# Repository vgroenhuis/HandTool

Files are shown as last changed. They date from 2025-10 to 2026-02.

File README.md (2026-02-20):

# HandTool
Handheld 6 DOF input device for robot control applications.

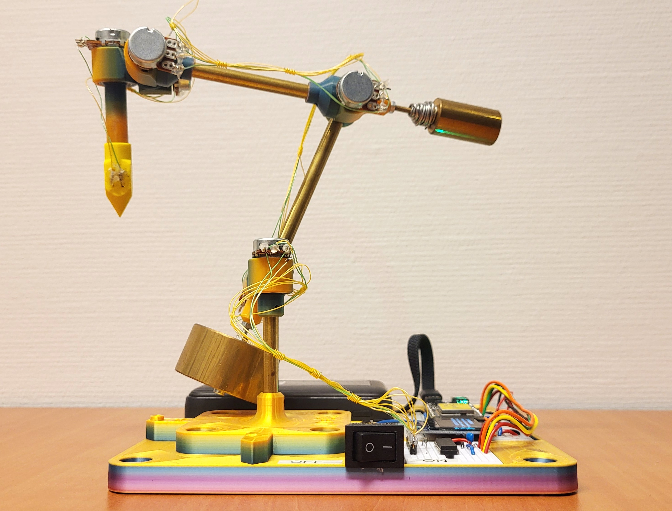
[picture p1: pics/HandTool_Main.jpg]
HandTool main view


# Introduction

HandTool is a 6 DOF input device intended for manipulating robot arms and other applications involving manipulation of rigid bodies. It is low-cost and fully open source.

The tool has six potentiometers connected together with 3D printed parts and brass shafts. The tool is balanced by two masses so that it mostly stays in position when released. It also has a pushbutton in the tip, intended to enable/disable dragging of some controlled object.

The tool is WiFi enabled; the microcontroller serves webpages and provides several HTTP endpoints providing data in JSON format. The idea is that it could dynamically connect to other WiFi-enabled robot arms.

# Electronics

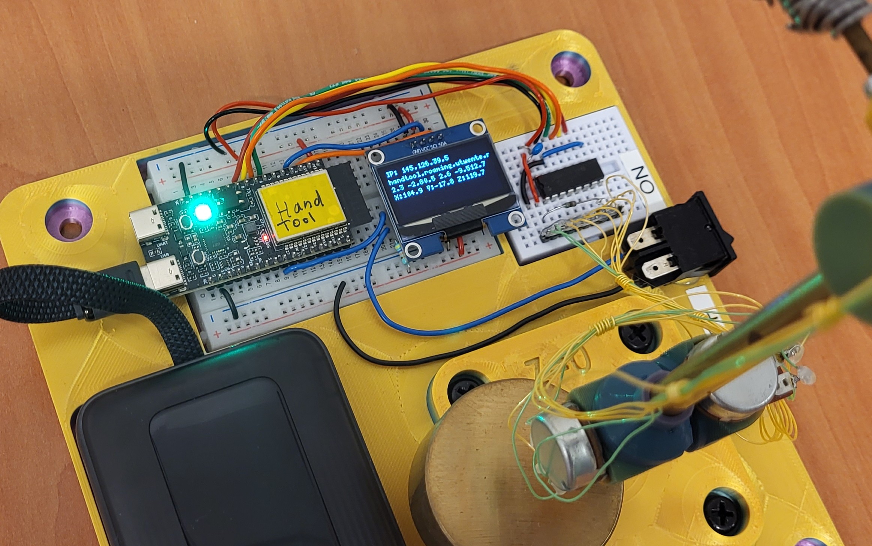
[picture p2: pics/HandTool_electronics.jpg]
HandTool main view


The microcontroller is an ESP32-C5-DevKitC-1. It is chosen for its 5 GHz WiFi capabilities, which is essential inside university buildings due to congestion in the 2.4 GHz band. A MCP3008 A/D unit measures the potentiometer values while a 1.3" OLED displays some status information.

# User interface

THe main user interface is accessed in a web browser at the device's address. The device connects to university's iotroam network, registered at iotroam.nl. A hostname can be coupled to its MAC address to give it a static hostname, such as handtool.roaming.utwente.nl . The IP address is also displayed on the screen, which is useful as it is dynamic and a change in IP address takes a few minutes to propagate through the DNS servers.

## 3D robot view

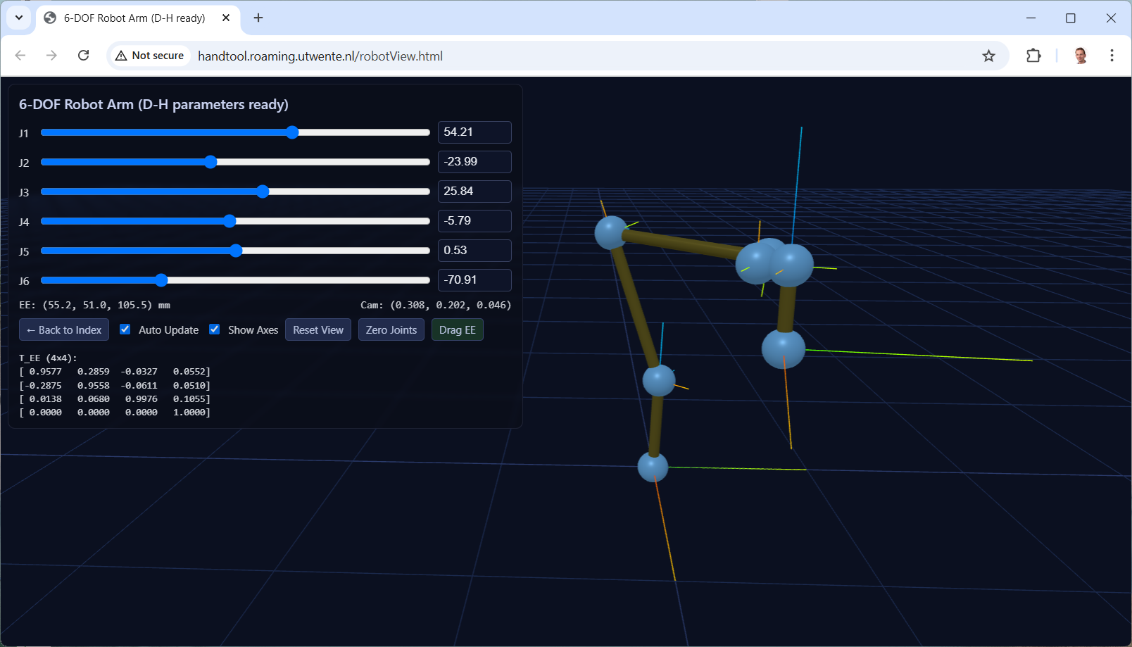
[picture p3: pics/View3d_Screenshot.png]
3D robot view


This screenshot shows a schematic rendering of the HandTool. If it is not connected, the sliders can be used to manipulate it.

## HTTP endpoints

The following HTTP endpoints are available:

- / Main page.
- /index.html Main page, same as /
- /robotView.html Open Robot View (3D)
- /allData JSON structure with all available data
- /angles JSON structure with joint angles in degrees
- /rawAdcValues JSON structure with raw ADC values
- /fk JSON structure with end-effector to robot coordinate transformation matrix
- /dhParams JSON structure with D-H parameters of the HandTool
- /serialAngles Enable/disable outputting angles to serial port
- /serialFK Enable/disable outputting end-effector coordinate frame to serial port
- /serialFrequency Control frequency of serial data

## Bill of Materials

1. 6x potmeter: WH148 compatible, 10KΩ. I used R16148-1A-2-B10K.
2. 6x ball bearing: 6700ZZ or equivalent. 15x10x4 mm.
3. Brass tubes, outer diameter 7 mm, wall thickness 0.5 mm. Lengths: 54 mm, 76 mm, 90 mm.
4. M3 threaded rod for small counterweight, 50 mm.
5. M3 screw (cheese head) for large counterweight, 44 mm. (Use 50 mm, cut to length).
6. Several M3 nuts.
7. M2 screw, 16 mm (to properly fix brass rods in joints).
8. M6 screws for mounting the base (flat head).

## Assembly instructions

3D print parts. Solidworks, STEP and 3MF files are available [here](CAD/v1_2024). Note that the JointHousing Solidworks file has six distinct configurations, with a total of nine printed parts. The pictured version was printed in rainbow PLA filament, starting with purple/blue on the buildplate and extending towards yellow. No supports are needed, but a brim is generally required.

7 mm brass rods (wall thickness 0.5 mm) are mostly press fitted in 3d printed parts. If the press fit becomes too loose then you can drill a small (1.8 or 1.9 mm) hole so you can tighten it with a M2 screw.

Small and large counterweights are custom made of brass in a workshop using a lathe. Use M3 threaded rods and/or screws and nuts to rigidly attach these to the correct joint. First balance the top part with the small counterweight by adjusting the separation distance. Then balance the whole hand tool with the large counterweight.

Electric wires should be thin and flexible. Solder these to the potentiometer leads and apply hot glue as stress relief, or else the wires may break off at the solder joints.

## History

The HandTool was first developed in 2024 to actuate a robot arm with identical kinematic configuration (apart from a scaling factor), so that direct joint control was possible and no forward/inverse kinematics was needed. See video [here](https://utwente.yuja.com/v/MamriRobot). The HandTool went through four iterations before arriving at v1.0. Earlier versions were not counter-weighted, but used friction in the joints to keep the given pose.

## Roadmap

Upcoming features

- Implement HTTP authentication.
- Improved design with more off-the-shelf parts instead of customized parts. Especially counterweights and links.
- Dedicated PCB for electronics.
- Calibrate zero position in software, saving offsets in filesystem.
- Additional communication protocols.
  - Examples: Bluetooth, MQTT, ROS2, ...
  - Want to implement it yourself? Clone the repository, implement it and make a pull request!

## Phyiscal devices

First HandTool at RaM [handtool.roaming.utwente.nl](http://handtool.roaming.utwente.nl/) (accessible from within University of Twente's network)

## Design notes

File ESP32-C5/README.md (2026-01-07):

# HandTool (ESP32-C5)

This repository contains firmware and resources for the HandTool project targeting the ESP32-C5.

Below is an image of the Hand Tool:

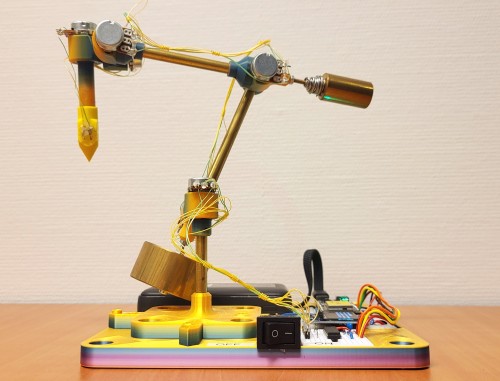
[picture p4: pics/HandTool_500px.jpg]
HandTool


The file `src/WifiCredentials.h` is not under version control. You can make your own. Example contents:

```
{
#pragma once
#define WIFI_CREDENTIALS {{"ssid","password"},{"ssid2","pasword2"}}
#define ADMIN_CREDENTIALS {"admin",""}
#define ALIAS_URL "https://raw.githubusercontent.com/vgroenhuis/roaming-wifi-manager/refs/heads/main/aliases/bssid_info.json"
}
```

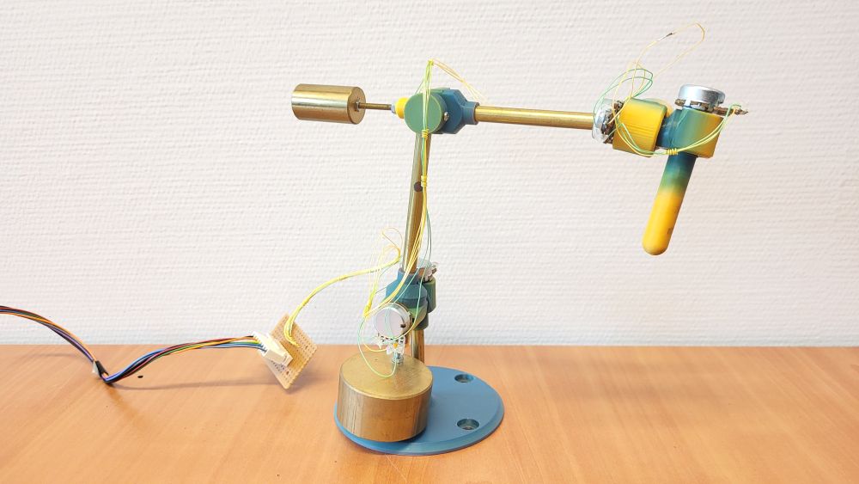
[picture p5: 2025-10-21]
pics/HandTool_1000px.jpg

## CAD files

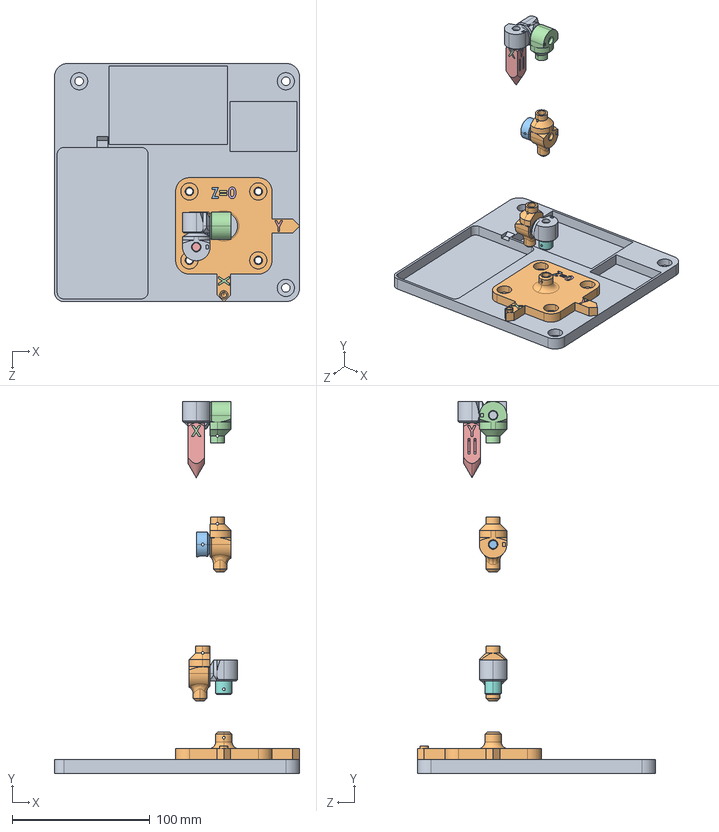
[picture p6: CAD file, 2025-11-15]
CAD/v1.1_2025/HandTool_With_Electronics_Assembly.STEP
178.0 x 270.0 x 173.0 mm
FrameForElectronics
Base_large
StickWithButton_J1bottom
StickWithButton_J1top_J5_J6 x 3
StickWithButton_J2_J3_Counterweight x 2
StickWithButton_J3bottom
StickWithButton_J2_J3
Stick2WithButton

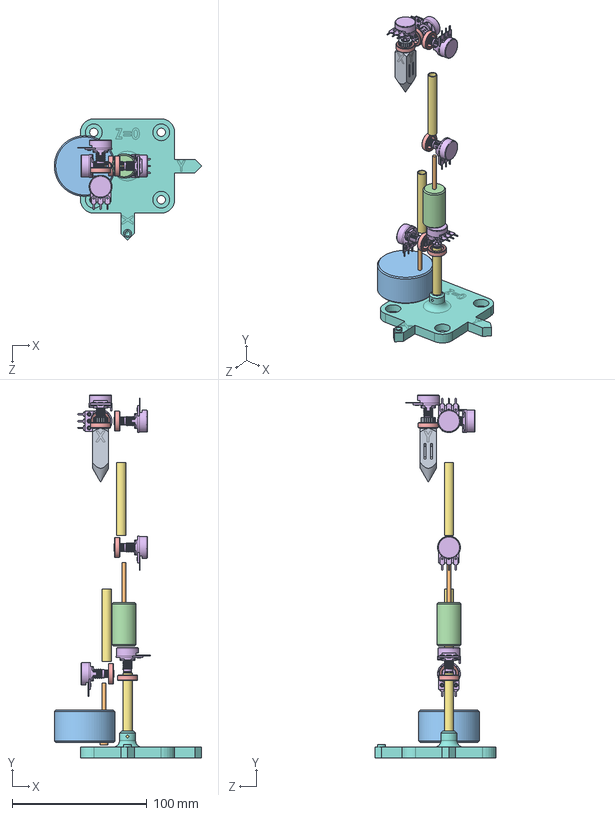
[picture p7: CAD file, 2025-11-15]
CAD/v1.1_2025/HandTool_Assembly.SLDASM
109.3 x 269.4 x 90.0 mm
Base_large
BrassLink x 3
Potmeter10K x 6
Bearing_6700ZZ x 6
CounterweightSmall
CounterweightLarge
M3_Rod x 2
Stick2WithButton

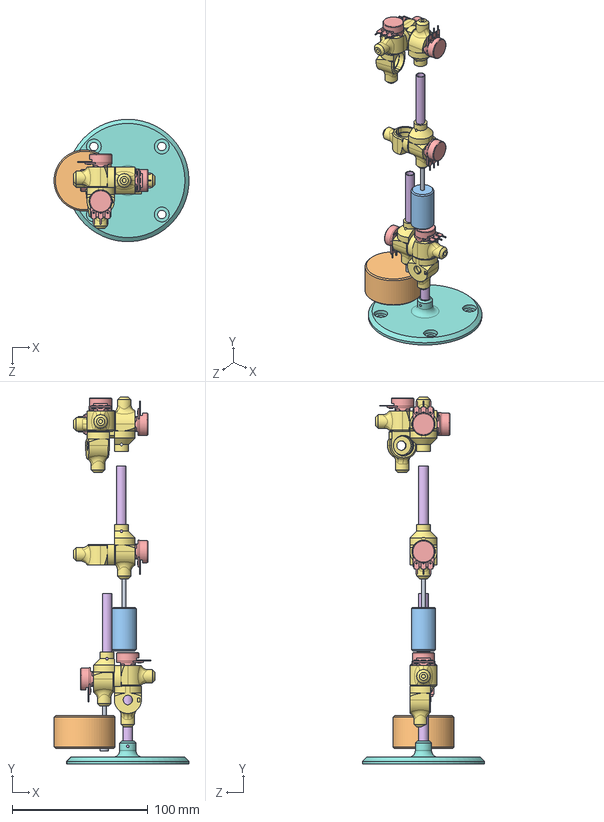
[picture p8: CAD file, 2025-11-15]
CAD/v1_2024/HandTool_Assembly.SLDASM
99.3 x 270.0 x 90.0 mm
Base
JointHousing x 9
BrassLink x 3
Potmeter10K x 6
Bearing_6700ZZ x 6
CounterweightSmall
CounterweightLarge
M3_Rod x 2

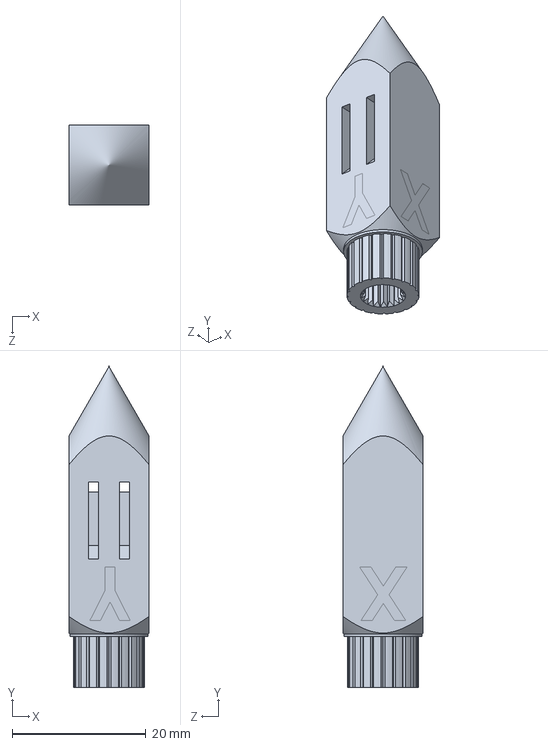
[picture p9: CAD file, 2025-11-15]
CAD/v1.1_2025/Stick2WithButton.SLDPRT
12.0 x 48.0 x 12.0 mm

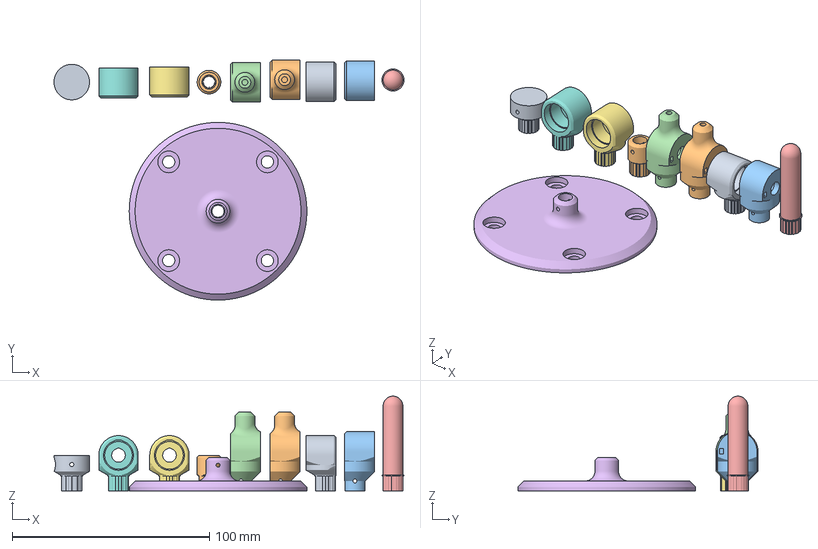
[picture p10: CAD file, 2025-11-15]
CAD/v1_2024/HandTool_PrintedParts_BambuSlicer.3mf
177.3 x 121.7 x 48.0 mm
JointHousing_J1top_J5_J6 x 3
JointHousing_J2_J3_Counterweight x 2
JointHousing_J2_J3
JointHousing_Stick
Base
JointHousing_J3bottom
JointHousing_J1bottom

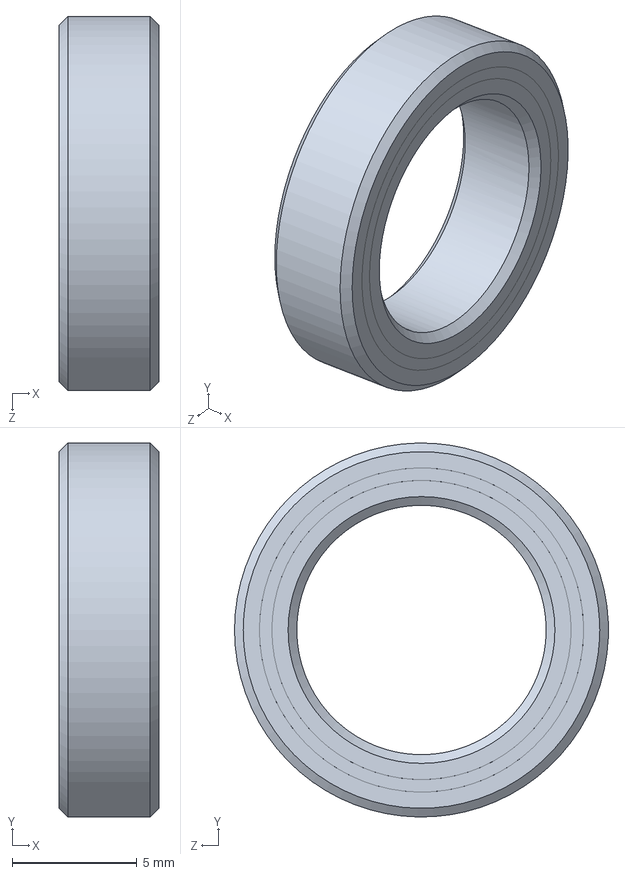
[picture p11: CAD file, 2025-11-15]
CAD/v1.1_2025/Bearing_6700ZZ.SLDPRT
4.00 x 15.0 x 15.0 mm

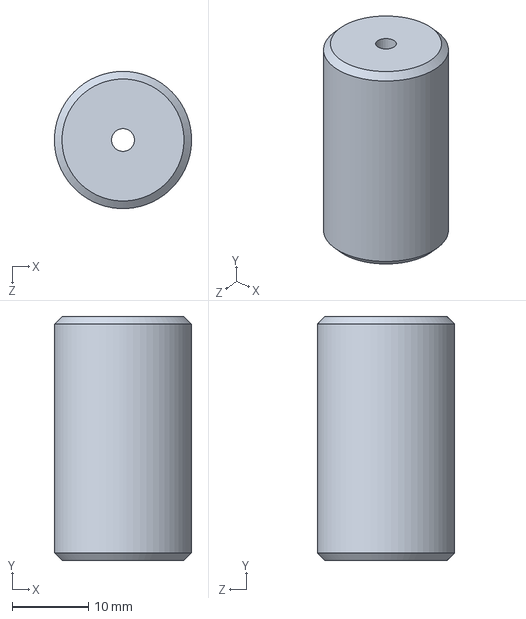
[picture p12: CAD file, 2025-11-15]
CAD/v1.1_2025/CounterweightSmall.SLDPRT
18.0 x 32.0 x 18.0 mm

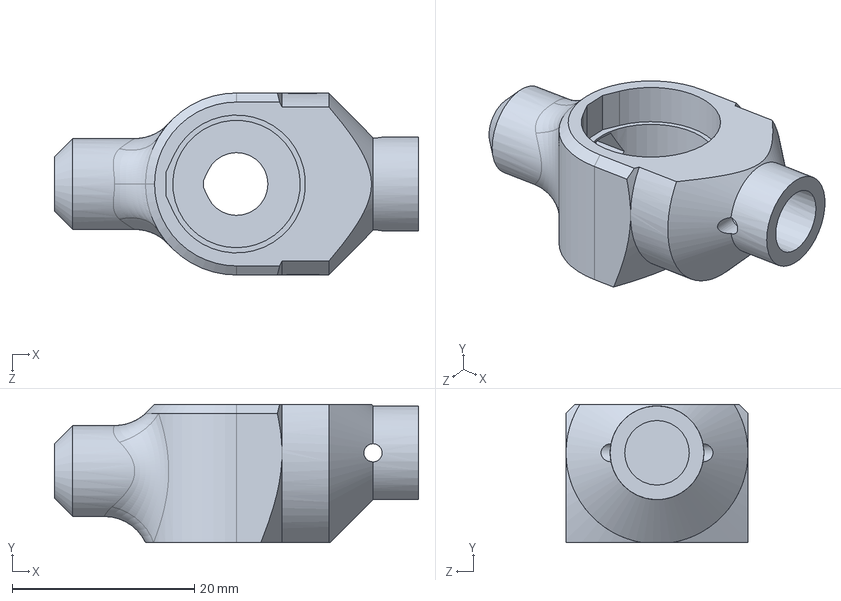
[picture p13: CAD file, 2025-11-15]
CAD/v1_2024/JointHousing.SLDPRT
40.0 x 15.2 x 20.0 mm

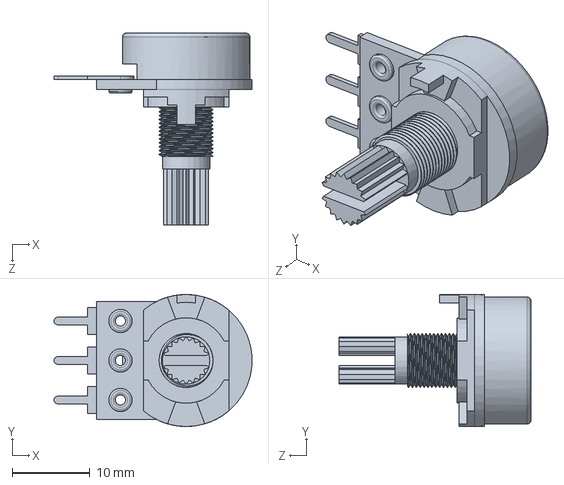
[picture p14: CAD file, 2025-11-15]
CAD/v1.1_2025/Potmeter10K.SLDPRT
25.5 x 17.0 x 24.7 mm

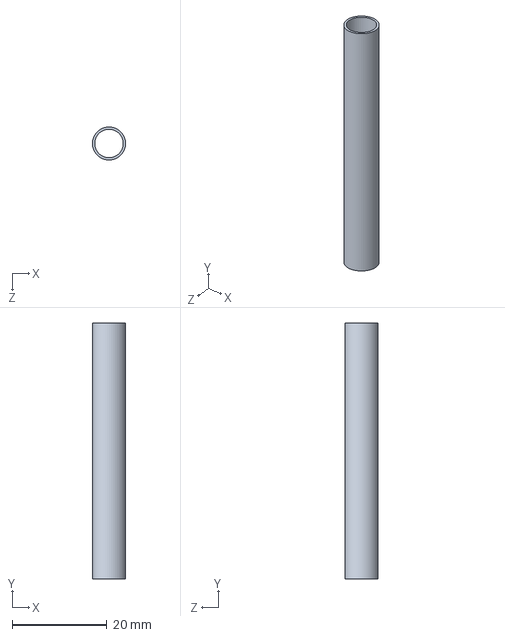
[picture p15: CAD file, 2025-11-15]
CAD/v1.1_2025/BrassLink.SLDPRT
6.99 x 54.0 x 7.00 mm

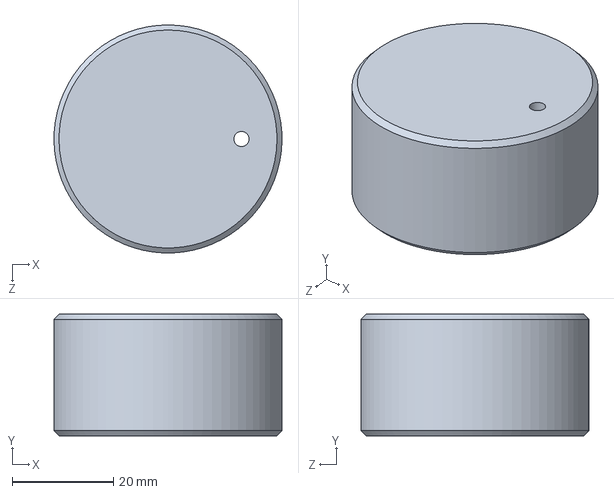
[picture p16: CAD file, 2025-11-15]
CAD/v1_2024/CounterweightLarge.SLDPRT
45.0 x 24.0 x 45.0 mm

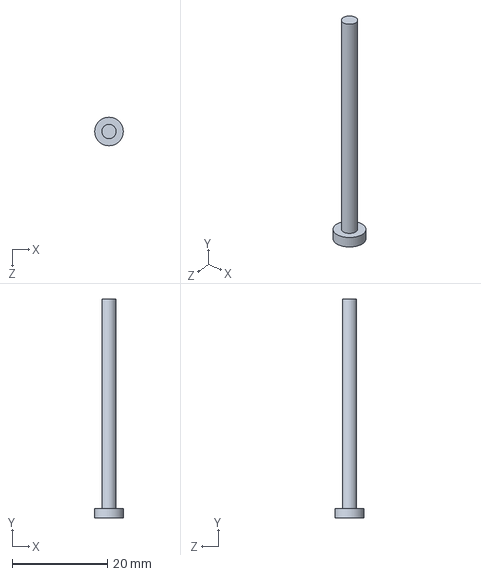
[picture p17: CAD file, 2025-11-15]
CAD/v1_2024/M3_Rod.SLDPRT
5.99 x 46.0 x 6.00 mm

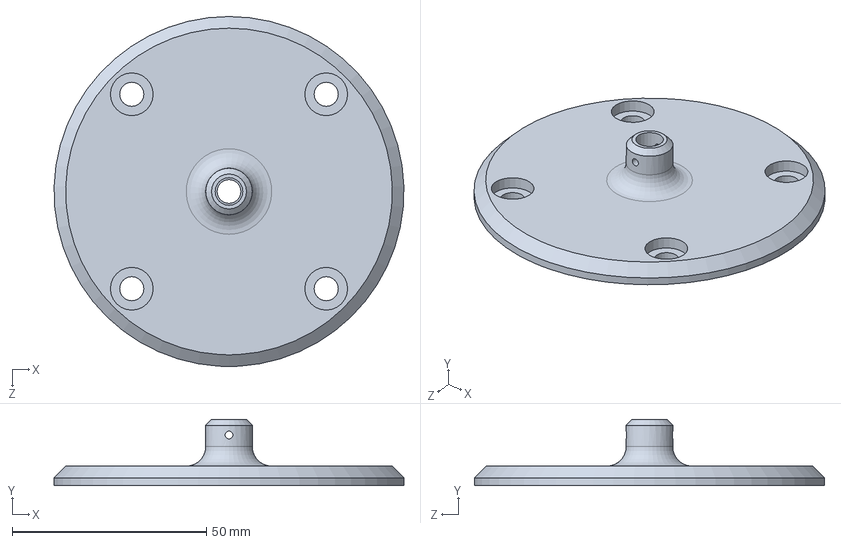
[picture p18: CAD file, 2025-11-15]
CAD/v1_2024/Base.SLDPRT
90.0 x 17.0 x 90.0 mm

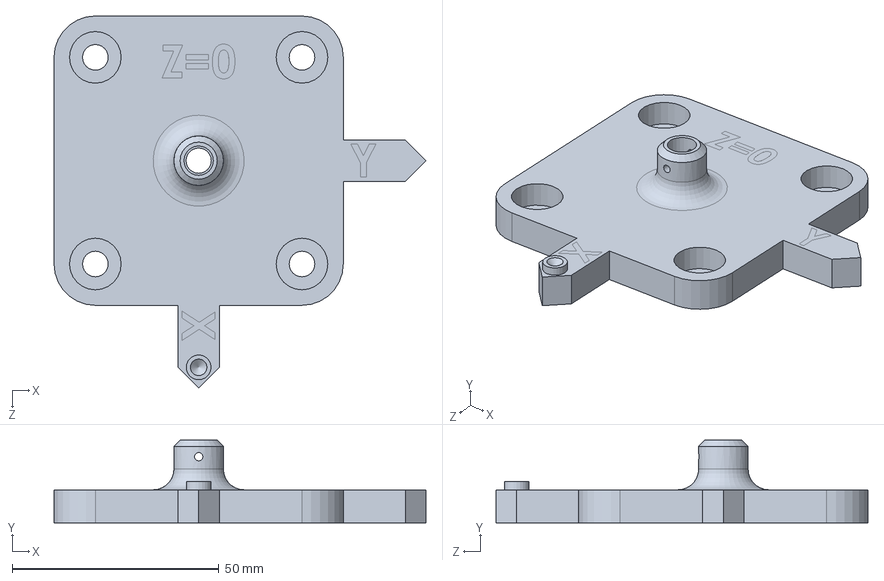
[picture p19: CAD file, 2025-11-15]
CAD/v1.1_2025/Base_large.SLDPRT
90.0 x 20.0 x 90.0 mm

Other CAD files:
CAD/v1_2024/Potmeter10K.SLDPRT
CAD/v1.1_2025/FrameForElectronics.SLDPRT
CAD/v1.1_2025/HandTool_With_Electronics_Assembly.SLDASM
CAD/v1.1_2025/Stick2WithButton_Adapter.SLDPRT
CAD/v1.1_2025/StickWithButton.SLDPRT
CAD/v1_2024/HandTool_PrintedParts.STEP

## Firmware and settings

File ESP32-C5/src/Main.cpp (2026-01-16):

#include <Arduino.h>
#include "WifiServer.h"
#include "Adc.h"
#include "Display.h"
#include "Kinematics.h"
#include <LittleFS.h>
#include <esp_sleep.h>

/*
void sleep_setup() {   
    esp_sleep_enable_ext1_wakeup_io(1<<4, ESP_EXT1_WAKEUP_ANY_LOW);
}
*/

/*
bool isPowerSwitchOn() {
    return digitalRead(4) == LOW;
}
*/

void init_file_system() {
    if (!LittleFS.begin(true, "/littlefs", 10, "littlefs")) {
        Serial.println("LittleFS Mount Failed");
    } else {
        //Serial.println("LittleFS Mounted Successfully");
    }
}

void setupHandTool() {
    //rgbLedWrite(LED_BUILTIN, 255, 255, 255);
    //rgbLedWrite(LED_BUILTIN, 255, 0, 0);
    Serial.begin(115200);
    delay(100);
    //sleep_setup();
    init_file_system();
    display_setup();
    robot_setup();
    kinematics_init();
    wifi_setup();
}

//if (isPowerSwitchOn()) {
        //rgbLedWrite(LED_BUILTIN, 30, 10, 0); // Orange during setup
    //}
    //rgbLedWrite(LED_BUILTIN, 0, 10, 0); // Green when setup complete



void setup() {
    analogReadResolution(12);
    pinMode(A5, INPUT); // Battery voltage ADC
    setupHandTool();
}

void printValuesPeriodically() {
    static unsigned long lastPrinted = 0;
    if (millis() - lastPrinted >= 1000) {
        lastPrinted = millis();
        // Print ADC readings to Serial
        Serial.print("Raw ADC:");
        for (uint8_t ch = 0; ch < 8; ++ch) {
            Serial.printf(" CH%u=%u", ch, raw_adc[ch]);
        }
        Serial.printf(" Battery: ADC5=%d Voltage=%.2fV", analogRead(A5), getBatteryLevel());
        Serial.println();
    }
}

/*
void startDeepSleep() {
    delay(10);
    display_message("Going to sleep...");
    WiFi.disconnect(true);
    WiFi.mode(WIFI_OFF);
    //rgbLedWrite(LED_BUILTIN, 255, 255, 255);
    delay(500);
    rgbLedWrite(LED_BUILTIN, 0, 0, 0);
    display_off();
    delay(10);
    esp_deep_sleep_start();
}

void testDeepSleep() {
    if (!isPowerSwitchOn()) {
        startDeepSleep();
    }
}
*/

void loopHandTool() {
    //testDeepSleep();
    sensors_loop();
    display_loop();
    wifi_loop();
    //printValuesPeriodically();
    //delay(1);
}

void loop() {
    loopHandTool();
}

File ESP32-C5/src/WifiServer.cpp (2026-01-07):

#include "WifiServer.h"
// #include <WiFi.h>
// #include <WebServer.h>
#include <Arduino.h>
// #include <HTTPClient.h>
// #include <WiFiClientSecure.h>
#include "Adc.h"
#include <LittleFS.h>
#include "Display.h"
#include "Kinematics.h"

#ifndef DISABLE_WIFI
RoamingWiFiManager manager;
#endif

/*
static unsigned long s_lastReconnect = 0;
static unsigned long s_lastStatusPing = 0;
*/

/*
WebServer server(80);
WiFiClientSecure client; // TLS required by server
HTTPClient heartbeatHttp;
bool heartbeatInitialized = false;
*/

// Serial output control flags
bool serialOutputAngles = false;
bool serialOutputFK = false;
unsigned long lastSerialOutput = 0;
unsigned long serialOutputInterval = 100; // ms between outputs (default 10Hz)

/*
const char* wifi_mac() {
    static String m;
    m = WiFi.macAddress();
    return m.c_str();
}

const char* wifi_ip() {
    static String ip;
    ip = WiFi.localIP().toString();
    return ip.c_str();
}

bool wifi_is_connected() {
    return WiFi.status() == WL_CONNECTED;
}
*/

// HTTP handler for /rawAdcValues - returns JSON with raw ADC readings
void handleRawAdcValues(AsyncWebServerRequest *request) {
    String json = "{";
    json += "\"valid\": ";
    json += mcp3008_present ? "true" : "false";
    json += ",";
    json += "\"values\": [";
    for (int i = 0; i < 8; ++i) {
        json += String(raw_adc[i]);
        if (i < 7) json += ",";
    }
    json += "]";
    json += "}";
    request->send(200, "application/json", json);
}

void handleFilteredAdcValues(AsyncWebServerRequest *request) {
    String json = "{";
    json += "\"valid\": ";
    json += mcp3008_present ? "true" : "false";
    json += ",";
    json += "\"values\": [";
    for (int i = 0; i < 8; ++i) {
        json += String(filtered_adc[i]);
        if (i < 7) json += ",";
    }
    json += "]";
    json += "}";
    request->send(200, "application/json", json);
}

// HTTP handler for /angles - returns JSON with six joint angles in degrees
void handleAngles(AsyncWebServerRequest *request) {
    String json = "{";
    json += "\"valid\": ";
    json += mcp3008_present ? "true" : "false";
    json += ",";
    json += "\"dragButtonPressed\": ";
    json += dragButtonPressed ? "true" : "false";
    json += ",";
    json += "\"angles\": [";
    for (int i = 0; i < 6; ++i) {
        json += String(angles_deg[i], 2);
        if (i < 5) json += ",";
    }
    json += "]";
    json += "}";
    request->send(200, "application/json", json);
}

// HTTP handler for /fk - returns JSON with 4x4 transformation matrix from base to end-effector
void handleForwardKinematics(AsyncWebServerRequest *request) {
    //float joint_angles[6];
    //for (int i = 0; i < 6; ++i) {
    //   joint_angles[i] = angles_deg[i];
    //}
    
    // Compute forward kinematics
    Matrix4x4 T = IDENTITY_MATRIX;
    //matrix_identity(T);

    if (mcp3008_present) {
        T = compute_forward_kinematics(angles_deg);
    }

    // Build JSON response with 4x4 matrix structure
    String json = "{";
    json += "\"valid\": ";
    json += mcp3008_present ? "true" : "false";
    json += ",";
    json += "\"dragButtonPressed\": ";
    json += dragButtonPressed ? "true" : "false";
    json += ",";
    json += "\"matrix\": [";
    for (int row = 0; row < 4; ++row) {
        json += "[";
        for (int col = 0; col < 4; ++col) {
            json += String(T.m[row][col], 6);  // 6 decimal places
            if (col < 3) json += ",";
        }
        json += "]";
        if (row < 3) json += ",";
    }
    json += "]";
    json += "}";
    
    request->send(200, "application/json", json);
}

void handleAllData(AsyncWebServerRequest *request) {
    // Compute forward kinematics
    Matrix4x4 T = IDENTITY_MATRIX;
    //matrix_identity(T);

    if (mcp3008_present) {
        T = compute_forward_kinematics(angles_deg);
    }

    // Build JSON response with 4x4 matrix structure
    String json = "{";
    json += "\"valid\": ";
    json += mcp3008_present ? "true" : "false";
    json += ",";
    json += "\"dragButtonPressed\": ";
    json += dragButtonPressed ? "true" : "false";
    json += ",";
    json += "\"rawAdcValues\": [";
    for (int i = 0; i < 8; ++i) {
        json += String(raw_adc[i]);
        if (i < 7) json += ",";
    }
    json += "],";
    json += "\"filteredAdcValues\": [";
    for (int i = 0; i < 8; ++i) {
        json += String(filtered_adc[i]);
        if (i < 7) json += ",";
    }
    json += "],";
    json += "\"jointAngles\": [";
    for (int i = 0; i < 6; ++i) {
        json += String(angles_deg[i], 2);
        if (i < 5) json += ",";
    }
    json += "],";
    json += "\"matrix\": [";
    for (int row = 0; row < 4; ++row) {
        json += "[";
        for (int col = 0; col < 4; ++col) {
            json += String(T.m[row][col], 6);  // 6 decimal places
            if (col < 3) json += ",";
        }
        json += "]";
        if (row < 3) json += ",";
    }
    json += "]";
    json += "}";
    
    request->send(200, "application/json", json);    
}

// Handler to enable/disable serial output of joint angles
void handleSerialAngles(AsyncWebServerRequest *request) {
    if (request->hasArg("enable")) {
        serialOutputAngles = (request->arg("enable") == "1" || request->arg("enable") == "true");
        request->send(200, "text/plain", serialOutputAngles ? "Angles output enabled" : "Angles output disabled");
    } else {
        request->send(400, "text/plain", "Missing 'enable' parameter");
    }
}

// Handler to enable/disable serial output of FK data
void handleSerialFK(AsyncWebServerRequest *request) {
    if (request->hasArg("enable")) {
        serialOutputFK = (request->arg("enable") == "1" || request->arg("enable") == "true");
        request->send(200, "text/plain", serialOutputFK ? "FK output enabled" : "FK output disabled");
    } else {
        request->send(400, "text/plain", "Missing 'enable' parameter");
    }
}

// Handler to set serial output frequency
void handleSerialFrequency(AsyncWebServerRequest *request) {
    if (request->hasArg("hz")) {
        float hz = request->arg("hz").toFloat();
        if (hz > 0 && hz <= 1000) {
            serialOutputInterval = (unsigned long)(1000.0 / hz);
            String response = "Serial output frequency set to " + String(hz, 1) + " Hz (" + String(serialOutputInterval) + " ms)";
            request->send(200, "text/plain", response);
        } else {
            request->send(400, "text/plain", "Frequency must be between 0.1 and 1000 Hz");
        }
    } else {
        String response = "Current: " + String(1000.0 / serialOutputInterval, 1) + " Hz (" + String(serialOutputInterval) + " ms)";
        request->send(200, "text/plain", response);
    }
}
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

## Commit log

2025-10-21 Fix image filename case in README
2025-10-21 Added ESP32 script and resized HandTool images
2025-10-22 Bugfixes SPI
2025-10-27 Added CAD model
    [Base.SLDPRT, Bearing_6700ZZ.SLDPRT, BrassLink.SLDPRT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]
2025-10-27 Written assembly readme
2025-10-27 Update README with assembly instructions link
    Added a link to assembly instructions in the README.
2025-10-27 Modify README with new links and section
    Updated links and added a section for physical devices.
2025-10-27 Fix link to assembly instructions in README
2025-10-27 Add Bill of Materials to README
    Added a Bill of Materials section with detailed components required for assembly.
2025-10-28 Update README with new features and link correction
    Updated the link for the first HandTool at RaM and added a new feature for software calibration.
2025-10-28 Various small changes, and changing Beest to Handtool
    [HandTool_PrintedParts.STEP, HandTool_PrintedParts_BambuSlicer.3mf]
2025-10-28 Several improvements and small fixes. Display is now used to display joint angles and end-effector XYZ position.
    [Display.cpp, Main.cpp]
2025-10-29 Correct device status badge link
    Fixed the device status badge link in README.md.
2025-10-30 Further improvements
    [partitions.csv]
2025-10-31 Enabled deep sleep mode and proper throttling of HTML, updated partition table, some minor improvements
    [partitions copy.csv, partitions.csv]
2025-10-31 Simplified partitions table
    [partitions copy.csv, partitions.csv]
2025-10-31 Refactor Device status into Physical devices section
    Removed the Device status section and integrated its content into the Physical devices section.
2025-10-31 Add status badge for Device2
2025-10-31 Update Device2 status badge URL in README
2025-10-31 Update device status section in README
    Removed individual device status badges and added a link to the device display page.
2025-10-31 Update link text for Vincent's physical devices
2025-10-31 Fix punctuation in materials list
    Corrected punctuation in the list of materials.
2025-11-03 Fix image link case sensitivity in README
2025-11-04 Added feature to output angles and/or forward kinematics data to serial port. Added screenshot of 3D view.
2025-11-04 Added CAD v1.1
    [Base_large.SLDPRT, Bearing_6700ZZ.SLDPRT, BrassLink.SLDPRT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]
2025-11-06 Set auto-wakeup every half an hour to trigger some battery drain activity, so that the powerbank does not go to sleep.
2025-12-18 reformatting, commas
    [partitions.csv]
2026-01-16 Disabled deep sleep mode. Switch now disconnects battery, to prevent draining the battery.
    [Main.cpp]
2026-10-20 ESP-IDF firmware (ESP32-C5-IDF): lab demos reports, OTA, WebSocket stream
    Port of the Arduino firmware to ESP-IDF 5.5, next to it. Same pages and
    HTTP endpoints; Wi-Fi settings in flash instead of RoamingWiFiManager,
    status reports to the CloSer lab demos page, over-the-air updates with
    rollback, a 50 Hz WebSocket stream (/ws), zero calibration saved in NVS,
    three.js served from the device, no halt when the ADC or display is missing.
    Claude-Session: https://claude.ai/code/session_01FSyTfhLHAAQNxCSAHJeZv8
2026-10-20 ESP32-C5-IDF 2.1.0: u8g2 display with proportional fonts, Wi-Fi state and RSSI; relative page URLs
    The display shows what Wi-Fi is doing while connecting (searching, joining,
    getting an address, why it failed, attempt) and the signal when connected.
    u8g2 core is vendored with only the fonts used. Pages use relative URLs so
    they also work through the lab demos site (HTTPS).
    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
2026-10-20 ESP32-C5-IDF 2.1.1: bottom display row fits (descenders were cut off)
    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
2026-10-23 ESP32-C5-IDF 2.2.0: restart reason in the boot report
    Sync closer_demo with the Turtle firmware: the boot report now says why the board restarted (power on, brownout, crash, watchdog, update, ...), it reports right after Wi-Fi comes back, and it shares one scan lock.
    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
